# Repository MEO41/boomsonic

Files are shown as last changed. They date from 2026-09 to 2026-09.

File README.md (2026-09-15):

# boomsonic

**A 500 N-class turbojet and a ≤ 25 kg supersonic airframe, designed from first principles with open-source tools.**

Conceptual design study for an aircraft that must reach and hold **Mach 1** under the Boom Prize rules.
Design point: **500 N net thrust at M 1.02, 5 000 m ISA**.

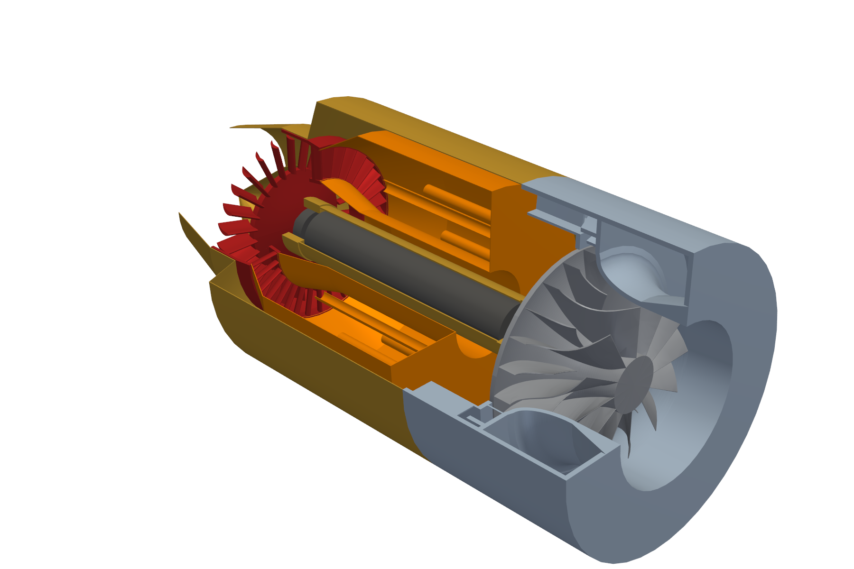
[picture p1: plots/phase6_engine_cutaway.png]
Engine cutaway


*Single-spool turbojet: centrifugal impeller and vaned diffuser (grey), annular vaporiser combustor (orange),
single-stage axial turbine (red). 187 mm diameter, 426 mm long, 6.85 kg.*

---

## Status

This is a **student learning project** and a **conceptual study**. Every number comes from a tool run or a cited
handbook relation, and the whole chain is reproducible from this repository — but **nothing has been built or
tested on hardware**, and several questions that decide whether this design survives are still open. They are
listed in [Open risks](#open-risks) and stated in full in [`docs/design_freeze.md`](docs/design_freeze.md).

Phases 0–6 are complete: requirements → airframe sizing → cycle and architecture trade → turbomachinery and rotor
dynamics → design freeze → CAD and 3D FE.

---

## What it came out as

### Engine — single-stage centrifugal turbojet

| | |
|---|---|
| Architecture | single spool: centrifugal compressor, annular combustor, axial turbine, convergent nozzle |
| Overall pressure ratio | 4.0 |
| Turbine inlet temperature | 1150 K |
| Airflow | 1.326 kg/s |
| TSFC | 0.164 kg/(N·h) |
| Spool speed | 75 000 rpm (105 % MCS = 78 750 rpm) |
| Impeller | Ti-6Al-4V, 12 main + 12 splitter blades, −15° exit backsweep, boreless hub |
| Impeller tip speed | 525 m/s (552 m/s at MCS) |
| Diffuser | vaneless gap, then 19 radial vanes to R4/R2 = 1.35, then axial deswirl |
| Turbine | single-stage axial, IN-713LC, 34 NGV / 28 rotor blades |
| Envelope / dry mass | **187 mm × 426 mm / 6.85 kg** |
| Sea-level static thrust | 631 N at 98.2 % speed (T4-limited) |

Efficiencies are quoted at the **fielded** level (η_c 0.70, η_t 0.75, η_b 0.95) — the level calibrated to reproduce
the TSFC of real commercial micro-turbojets, not the optimistic level the design tools predict.

### Aircraft — 0.30 m² wing, nose-pitot intake

| mass item | kg |
|---|---|
| engine (calibrated) | 6.85 |
| engine accessories | 1.60 |
| structure | 3.82 |
| landing gear + drag chute | 1.27 |
| fuel system | 0.40 |
| systems, avionics, instrumentation | 2.02 |
| growth allowance (15 %) | 1.13 |
| fuel (sortie + reserve + unusable) | 2.98 |
| **TOGW** | **20.09** |
| **margin to the 25 kg limit** | **4.91** |

| performance | nominal wave drag | pessimistic wave drag |
|---|---|---|
| **dash thrust margin at M 1.02 / 5 km** (target +25 %) | **+54.7 %** | **+28.5 %** |
| brake release to M 1.02 at 5 km | 27.7 s | 27.9 s |
| minimum excess thrust, transonic acceleration | 177 N | 116 N |
| 3 g sustained turn at M 0.9 / 5 km | +283 N | +283 N |
| ground roll / landing (flaps + chute) | 46 m / 175 m | |

> The **worst corner** (η_c 0.66, combustor +1σ, pessimistic drag) gives **+21.8 %, below the 25 % target.**
> It has not been re-run on the Phase 4 engine.

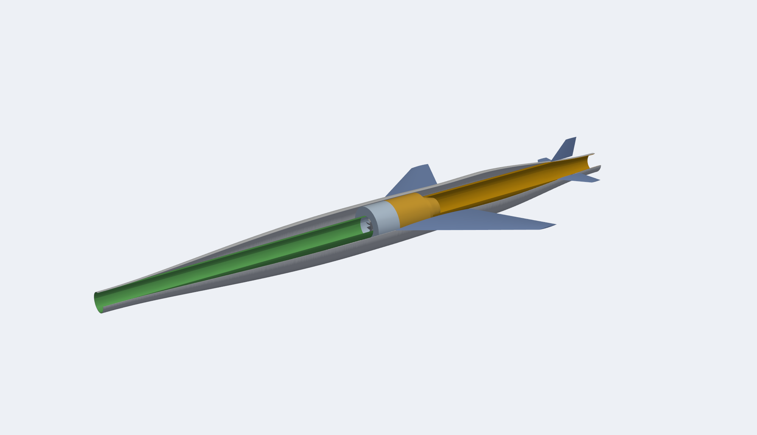
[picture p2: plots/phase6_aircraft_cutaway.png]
Aircraft cutaway


*Airframe with the intake duct (green), engine (grey/orange) and jetpipe (yellow). 2.7 m long, 217 mm fuselage
diameter, engine face at x = 1.315 m.*

---

## Selected results

### Architecture trade — why centrifugal

The Phase 3R trade swept OPR, spool speed and exit backsweep, screening each design for impeller stress feasibility
before evaluating it. Bars are engine diameter, calibrated dry mass, dash margin at pessimistic drag, and worst-corner
margin. The chosen point is OPR 4 / 75 krpm / −15°.

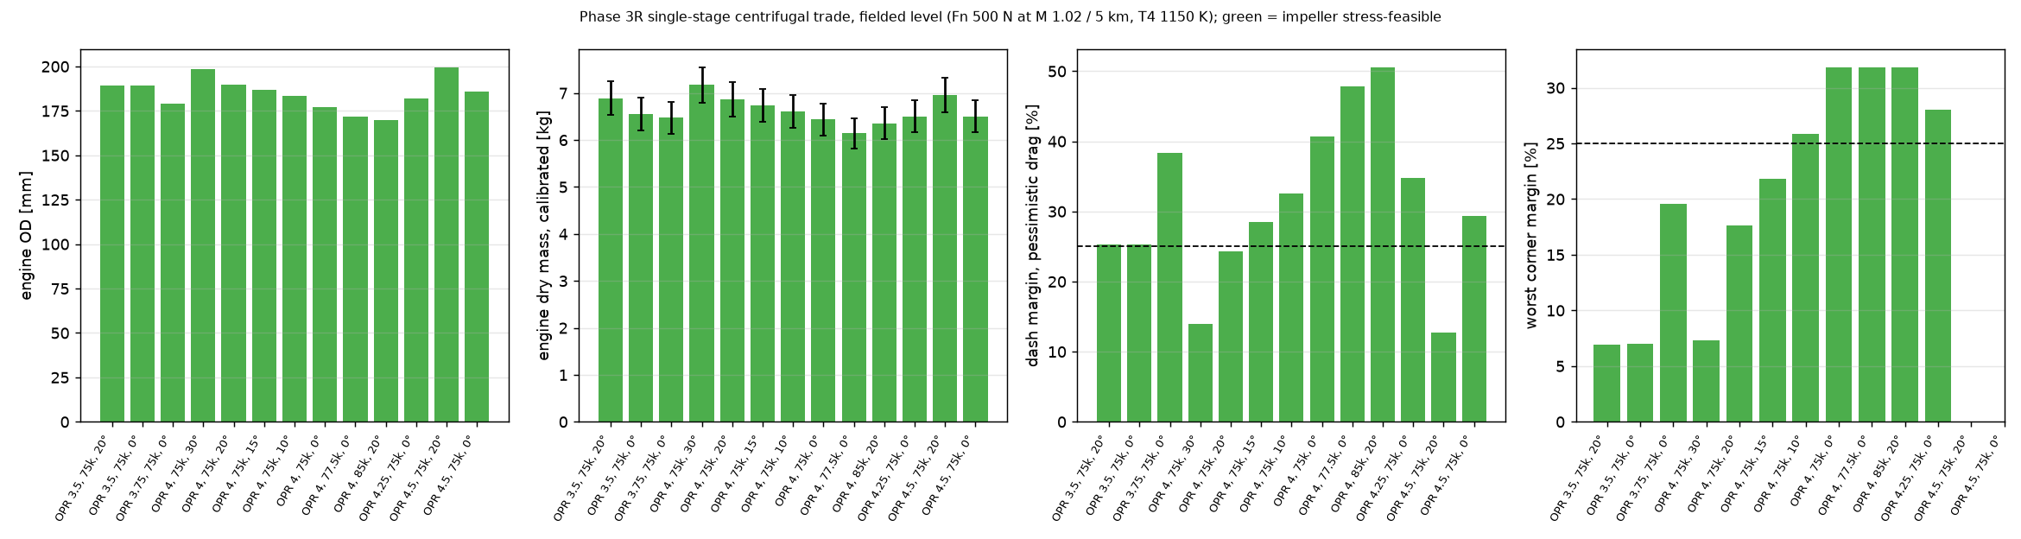
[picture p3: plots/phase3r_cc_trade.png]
Phase 3R centrifugal trade


### Off-design on real component maps

Thrust deck, sea-level-static running line and the flown sortie — computed in pyCycle with **TurboFlow-generated
compressor and turbine maps**, not placeholder map shapes.

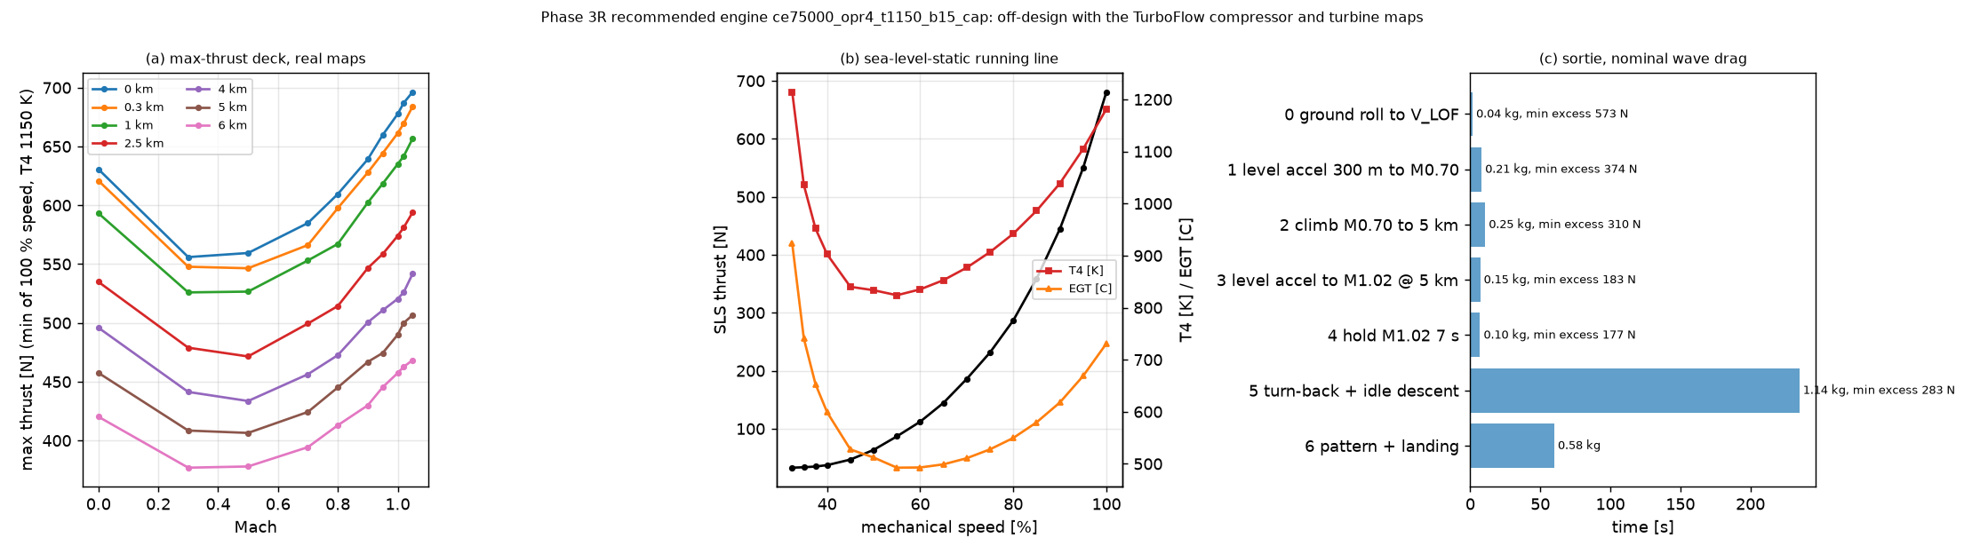
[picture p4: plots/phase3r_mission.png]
Phase 3R mission


### Rotor dynamics

Campbell diagram and mode shapes for the 32 × 25.6 mm tube shaft on damped supports. Three criticals at
8 335 / 14 383 / 105 571 rpm with amplification factors 2.64 / 1.28 / 29.09 — an **API-style separation-margin check
passes**, with the running range (grey) clear of the first two.

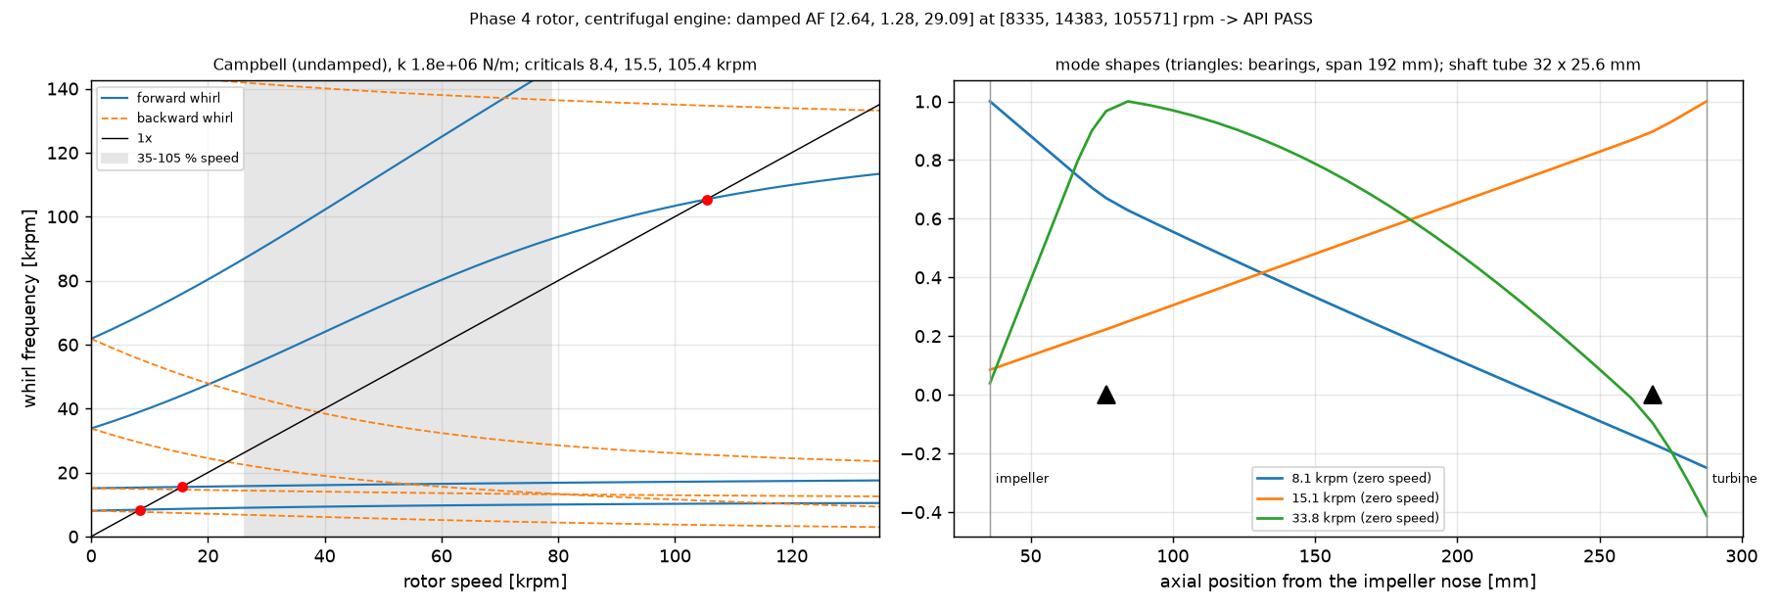
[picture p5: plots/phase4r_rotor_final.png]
Rotor dynamics


### 3D impeller stress

Cyclic-sector FE of the impeller passage, von Mises against Ti-6Al-4V minimum yield (622 MPa at temperature).
The exducer blade root sits on its limit by construction; the 3D model confirms the 1D sizing.

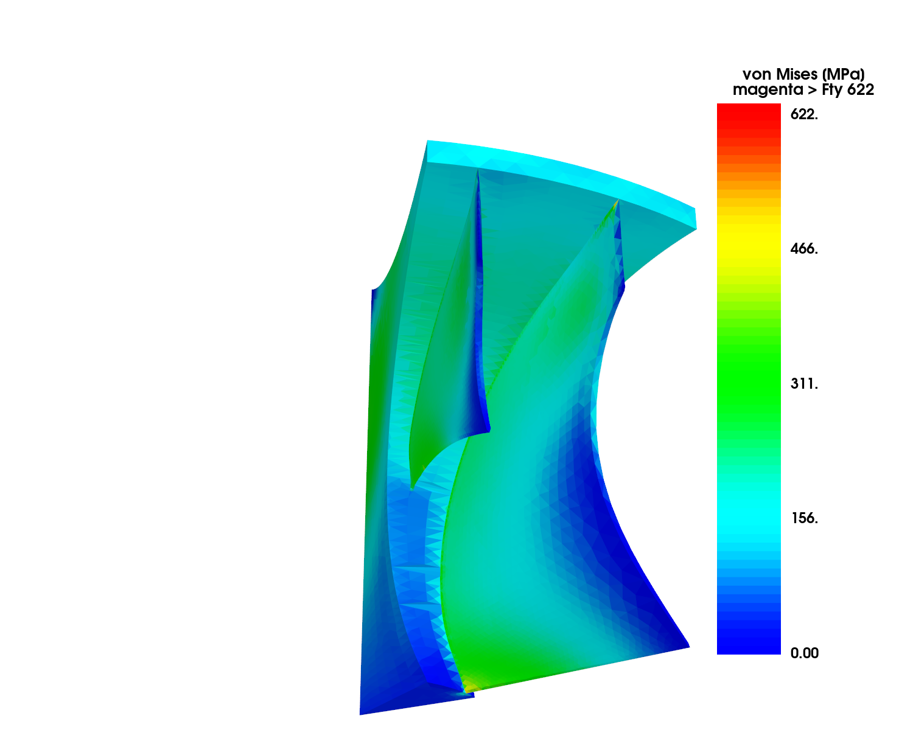
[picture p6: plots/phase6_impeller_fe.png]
3D impeller FE


More figures in [`plots/`](plots/) — constraint diagram, drag polar, area distribution, mass budget, cycle trade,
backsweep sweep, turbo-design cross-check, critical-speed map, and the CAD renders.

---

## Open risks

None of these is resolved. They are the reason this is a snapshot and not a closed design.

| risk | status |
|---|---|
| **Compressor surge margin** — no validated prediction method exists for a vaned-diffuser stage of this type. The peak-of-characteristic surrogate **failed its only validation** against NASA HECC data (measured 8.4 % vs surrogate ≥ 73 %). | **OPEN — top risk** |
| **Surge margin in the idle range** — 8.4–8.7 % on the ground running line; a start/handling bleed was proposed but never sized or integrated. | OPEN |
| **Combustor shortened 20 %** for rotor dynamics; combustion performance unverified at the shorter length. | OPEN |
| **Diffuser vane count excites the exducer at idle** — a live high-cycle-fatigue concern until the vane count is redesigned. | OPEN |
| **No rig or bench test.** Nothing here has been validated on hardware. | OPEN |
| Exducer root at yield at MCS by construction; turbine on its 350 MPa root limit; damped bearing cartridge not designed. | carried |

---

## How it was done

Every phase ends by handing the next decision to a human; nothing proceeds without that. Every non-trivial decision
is logged in [`design_log.md`](design_log.md) with the tool, the inputs, the outputs and why the choice won.

**Ground rule: no guessing.** Where a tool could not answer a question, that is recorded rather than filled in.

Tools are verified against closed-form or published results *before* being trusted, and the defects found along the
way are documented in [`tools_survey.md`](tools_survey.md) — including a genuine bug in TurboFlow's centrifugal slip
model (it takes `cos` of an angle in degrees), which is patched at run time and evidenced by a dedicated script.

| tool | used for |
|---|---|
| [pyCycle](https://github.com/OpenMDAO/pyCycle) / OpenMDAO | thermodynamic cycle, off-design, engine deck |
| [TurboFlow](https://github.com/turbo-sim/TurboFlow) | centrifugal compressor and axial turbine meanline design + maps |
| [turbo-design](https://github.com/nasa/turbo-design) (NASA) | independent centrifugal cross-check |
| [TurboDesigner](https://github.com/Turbodesigner/turbodesigner) | axial compressor meanline |
| [Cantera](https://cantera.org/) | combustion, real-gas check |
| [ADRpy](https://github.com/sobester/ADRpy) / [AeroSandbox](https://github.com/peterdsharpe/AeroSandbox) | constraint diagram, drag build-up |
| [ROSS](https://github.com/petrobras/ross) | rotor dynamics |
| [CadQuery](https://github.com/CadQuery/cadquery) + gmsh + scikit-fem | CAD, meshing, 3D FE |

---

## Repository layout

```
scripts/       phase0_tools/          tool smoke tests and verification
               phase1_requirements/   operating point and mission
               phase2_airframe/       constraint diagram, drag, mass budget
               phase3_cycle/          cycle model, architecture trade, centrifugal design
               phase4_turbomachinery/ maps, operability, stress, rotor dynamics
               phase6_cad/            CAD, 3D FE, rendering
               phase7_afterburner/    afterburner cycle, envelope, nozzle trade, closure
docs/          one report per phase; design_freeze.md is the status snapshot
data/          generated results (committed)
plots/         generated figures
cad/           STEP solids (engine_assembly.step, engine_with_afterburner_assembly.step)
axial/         the axial + axial-centrifugal branch, self-contained
```

The **axial branch is kept separate** under [`axial/`](axial/README.md). A 6-stage axial engine was taken to its own
freeze for comparison; it is not the baseline, and which architecture goes forward is still an open decision.
Keeping it in its own tree means axial numbers cannot leak into continued centrifugal work.

## Running it

Python 3.12 via [`uv`](https://github.com/astral-sh/uv), in three virtual environments (ADRpy and TurboFlow need
NumPy 1; pyCycle and the CAD stack need NumPy 2).

```powershell
uv venv --python 3.12 .venv      ; $env:VIRTUAL_ENV="$PWD\.venv";     uv pip install -r requirements-np2.txt
uv venv --python 3.12 .venv-np1  ; $env:VIRTUAL_ENV="$PWD\.venv-np1"; uv pip install -r requirements-np1.txt
uv venv --python 3.12 .venv-cad  ; $env:VIRTUAL_ENV="$PWD\.venv-cad"; uv pip install -r requirements-cad.txt
```

Check the toolchain, then reproduce the baseline engine:

```powershell
.venv\Scripts\python scripts\phase0_tools\smoke_pycycle.py                          # toolchain check
.venv\Scripts\python scripts\phase3_cycle\cc_trade.py run 4.0:75000:-15             # the baseline engine
.venv\Scripts\python scripts\phase3_cycle\cc_mission.py ce75000_opr4_t1150_b15_cap  # deck + sortie on real maps
.venv\Scripts\python scripts\phase4_turbomachinery\cc_closure.py                    # airframe mass closure
```

Phase 7 (afterburner) — verify first, then the study:

```powershell
.venv\Scripts\python scripts\phase7_afterburner\verify_ab_cycle.py      # regression + closed form + Cantera
.venv\Scripts\python scripts\phase7_afterburner\ab_envelope.py --regress # dry deck vs the frozen deck
.venv\Scripts\python scripts\phase7_afterburner\ab_design_point.py      # Tt7 sweep, duct Mach, thermal choking
.venv\Scripts\python scripts\phase7_afterburner\ab_envelope.py          # how far past Mach 1, on real maps
.venv\Scripts\python scripts\phase7_afterburner\ab_hardware.py          # diffuser, flameholder, Cantera stability
.venv\Scripts\python scripts\phase7_afterburner\ab_nozzle_trade.py      # three nozzle concepts + fixed reference
.venv\Scripts\python scripts\phase7_afterburner\ab_closure.py           # mass and 25 kg closure
.venv-cad\Scripts\python scripts\phase7_afterburner\ab_cad.py          # CAD: engine_with_afterburner_assembly.step
.venv-cad\Scripts\python scripts\phase7_afterburner\ab_render.py       # plots/phase7_ab_cutaway.png, _section.png
```

Full per-phase command reference: [`docs/running_the_code.md`](docs/running_the_code.md).

## Documents

| | |
|---|---|
| [`turbojet_500N_mission_brief.md`](turbojet_500N_mission_brief.md) | the brief and its binding ground rules |
| [`docs/design_freeze.md`](docs/design_freeze.md) | **status snapshot: the design and every open risk** |
| [`docs/phase3r_centrifugal.md`](docs/phase3r_centrifugal.md) | cycle and centrifugal compressor design |
| [`docs/phase4r_centrifugal.md`](docs/phase4r_centrifugal.md) | maps, operability, stress, rotor dynamics |
| [`docs/phase6_cad.md`](docs/phase6_cad.md) | CAD, 3D FE, airframe integration |
| [`docs/phase7_afterburner.md`](docs/phase7_afterburner.md) | afterburner: +79 % thrust, what actually caps the envelope, the nozzle trade |
| [`design_log.md`](design_log.md) | every decision, with numbers |
| [`tools_survey.md`](tools_survey.md) | tool survey and the defects found |
| [`axial/README.md`](axial/README.md) | the axial branch |

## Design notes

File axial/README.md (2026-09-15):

# `axial/` — the axial and axial-centrifugal compressor work

Everything in this directory belongs to engine architectures that are **not** the project baseline.
It is kept for the record and is separated from the repo root so that continued development of the
**centrifugal** engine cannot pick up an axial number by accident.

| | |
|---|---|
| **Status** | Not the baseline. Which engine goes forward is still an open decision of `docs/design_freeze.md`. |
| **Pure axial** | 6 stages, OPR 5, 80 000 rpm, tag `ax80000_opr5_t1150_n6_cap_3r`. Taken to its own freeze: `axial/docs/design_freeze_axial.md`. |
| **Axial-centrifugal ("option B")** | 1–2 axial stages + 1 centrifugal, Phase 3b / Phase 4. Superseded; kept for the record only. |
| **Open risks** | Unchanged by this reorganisation. The axial freeze's open risks (unvalidated stacking model R4.1, idle 77.5 % forcing an engine-off descent, unsourced variable-geometry hardware, start not analysed, blade roots at 96 % of Fty, blade resonances) and the Phase 6A risks R6A.1–R6A.6 must not be presented as resolved. |

## Layout

```
axial/
  scripts/
    phase3_cycle/           ax_trade.py, axial_sweep.py, axicent_sensitivity.py
    phase4_turbomachinery/  ax_*.py (Phase 4A), operability.py + sweeps (Phase 4 axial),
                            ac_operability.py / impeller_check_ac.py / plot_optionB.py (option B),
                            axial_blockage_screen.py, check_turbodesigner_blockage.py
    phase6a_axial_cad/      packaging and mass CAD of the axial core + variable geometry
  data/
    phase3ax/   phase3ax_trade.csv        Phase 3A-R cycle/compressor designs
    phase4ax/                             Phase 4A operability, rotor, mission, closure
    phase4/                               Phase 4 axial + option-B maps (TurboFlow), map parts
    phase6a/                              Phase 6A parameters, clash, mass
    phase4_*.csv|json                     Phase 4 axial running lines, sweeps, rotordynamics
    phase3_axicent_*.csv                  option-B screens and sensitivity
  docs/                     phase4a_axial.md, design_freeze_axial.md, phase4_operability.md,
                            phase4_rotordynamics.md, phase4_optionB_checks.md, phase6a_axial_cad.md
  plots/                    phase4a_*.png, phase4_operability.png, phase4_optionB_operability.png,
                            phase4_campbell.png, phase4_critical_speed_map.png, phase4_rotor_*.png
  cad/
    parts/                  axial core + variable-geometry STEP solids
    axial_core_assembly.step, axial_vg_assembly.step
```

## How the split works

Scripts here keep **two** roots:

* `ROOT` — the repo root, unchanged in meaning. Shared modules (`cycle_model`, `arch_trade`,
  `engine_mass`, `rotor_model`, `cadlib`, …) and shared data (`data/phase3/`, `data/phase3r/`) are
  still reached through it, so nothing was duplicated.
* `AXROOT` — this directory. Every axial artefact (data, plots, cad) is written and read through it.

Each script inserts its original shared directory on `sys.path`, so its imports resolve exactly as
before the move.

### Five axial-named modules deliberately stayed in the shared tree

They could not move: the live **centrifugal** entry points import them.

| module (still in `scripts/`) | imported by | what is used |
|---|---|---|
| `phase3_cycle/axial_design.py` | `arch_trade.py` (module level) → `cc_trade.py` | axial meanline design, for the architecture trade |
| `phase3_cycle/axicent_design.py` | `arch_trade.py` (module level) → `cc_trade.py` | axial-centrifugal design, for the architecture trade |
| `phase4_turbomachinery/axial_map.py` | `cc_mission.py`, `cc_benchmark.py` | `build_compressor_lines`, `compressor_mapdata`, `turbine_mapdata` — generic map → pyCycle helpers, not axial-specific |
| `phase4_turbomachinery/axial_offdesign.py` | `cc_mission.py`, `cc_benchmark.py`, `ac_offdesign.py` | the `Choked` exception; `Compressor` only on the axial path |
| `phase4_turbomachinery/ac_offdesign.py` | `cc_mission.py`, `cc_benchmark.py` | `PureCC` and `CentrifugalMap` — the **pure centrifugal** off-design model lives in this file |

`rotordynamics.py`, `rotordynamics_damped.py`, `rotordynamics_stiffening.py` and `rotor_model.py`
also stayed, because `cc_rotor.py` imports them. Their `__main__` studies are the pure-axial rotor,
so those scripts write their results here, into `axial/data/` and `axial/plots/`.

## Commands

Run from the **repo root**, as before.

### Phase 3A-R / 4A (pure axial, taken to its freeze)

```powershell
.venv\Scripts\python axial\scripts\phase3_cycle\ax_trade.py grid                     # fielded compressor grid (P3_DATA=phase3ax set inside)
.venv\Scripts\python axial\scripts\phase3_cycle\ax_trade.py run 80000                # full chain at one speed (omit rpm: all speeds)
.venv\Scripts\python axial\scripts\phase3_cycle\ax_trade.py compile                  # axial/data/phase3ax_trade.csv
$t = "ax80000_opr5_t1150_n6_cap_3r"
.venv\Scripts\python axial\scripts\phase4_turbomachinery\ax_rotor_stress.py $t       # blade roots, discs, blade modes (+ FE verification)
.venv\Scripts\python axial\scripts\phase4_turbomachinery\ax_operability.py $t one 15 0.10 1.6   # one VG configuration per process (parallel)
.venv\Scripts\python axial\scripts\phase4_turbomachinery\ax_operability_summary.py $t          # idle per configuration (AXOP_SM_MIN)
$env:AXOP_A8_N = "0.80"; .venv\Scripts\python axial\scripts\phase4_turbomachinery\ax_operability.py $t final 15 0.10 2.0   # adopted VG
.venv\Scripts\python axial\scripts\phase4_turbomachinery\ax_rotor.py $t 80           # rotor-dynamics sweep (ROSS); 2nd arg = idle % for the API check
.venv\Scripts\python axial\scripts\phase4_turbomachinery\ax_transient.py $t          # acceleration (~45 min; AXTR_NS=0.8,0.775 re-runs a subset)
.venv\Scripts\python axial\scripts\phase4_turbomachinery\ax_mission.py $t            # engine deck + idle (AXM_REUSE_DECK=1 reuses the deck)
.venv\Scripts\python axial\scripts\phase4_turbomachinery\ax_closure.py $t            # engine update + closure (incl. engine-off descent)
.venv\Scripts\python axial\scripts\phase4_turbomachinery\ax_plots.py $t              # axial/plots/phase4a_*.png
```

### Phase 6A (axial packaging and mass CAD; exploratory only)

```powershell
.venv\Scripts\python axial\scripts\phase6a_axial_cad\make_params_axial.py    # parameter sheet + VG actuation loads
.venv\Scripts\python axial\scripts\phase6a_axial_cad\ax_flowpath_check.py    # flow-path area / choking capacity per station
.venv-cad\Scripts\python axial\scripts\phase6a_axial_cad\ax_engine_cad.py    # core engine solids -> axial/cad/parts/
.venv-cad\Scripts\python axial\scripts\phase6a_axial_cad\ax_vg_cad.py        # VIGV, stage-3 bleed, variable nozzle mechanisms
.venv-cad\Scripts\python axial\scripts\phase6a_axial_cad\ax_clash.py         # envelope, interference, clearances (~3 min)
.venv-cad\Scripts\python axial\scripts\phase6a_axial_cad\ax_mass_compare.py  # CAD vs the raw bottom-up mass model
```

### Phase 4 on the early pure axial (operability, rotor dynamics)

The map runners live in the shared tree and are steered by environment variables; point `MAP_DIR`
at `axial/data/phase4` for axial tags.

```powershell
.venv\Scripts\python axial\scripts\phase4_turbomachinery\check_turbodesigner_blockage.py   # evidence for the Phase 3 blockage error
$env:P3_OPR=5; $env:P3_CASES="axial:0"; $env:P3_TURB_CAP=1; $env:P3_CC_REF=0.794; $env:P3_TAG_SUFFIX="_blk"; .venv\Scripts\python scripts\phase3_cycle\arch_trade.py
$env:MAP_DIR="axial/data/phase4"; bash scripts/phase4_turbomachinery/run_turbine_map.sh ax0_opr5_t1150_cap_blk
.venv\Scripts\python axial\scripts\phase4_turbomachinery\operability.py ax0_opr5_t1150_cap_blk      # stacking map, running lines, variable IGV
.venv\Scripts\python axial\scripts\phase4_turbomachinery\nozzle_sweep.py ax0_opr5_t1150_cap_blk 1.3,1.6,2.0
.venv\Scripts\python axial\scripts\phase4_turbomachinery\bleed_sweep.py ax0_opr5_t1150_cap_blk 0.1,0.2,0.3
.venv\Scripts\python axial\scripts\phase4_turbomachinery\running_line_axi5.py                      # bracket with the NPSS AXI5 map
.venv\Scripts\python axial\scripts\phase4_turbomachinery\plot_operability.py
.venv\Scripts\python scripts\phase4_turbomachinery\rotordynamics_verify.py   # shared: ROSS verification (writes data/phase4_rotordynamics_verification.json)
.venv\Scripts\python scripts\phase4_turbomachinery\rotordynamics.py          # shared module, axial study -> axial/data, axial/plots
```

### Option B checks (axial-centrifugal) and method benchmark

```powershell
.venv\Scripts\python axial\scripts\phase4_turbomachinery\impeller_check_ac.py    # check 1: impeller stress, both AC variants
$env:MAP_DIR="axial/data/phase4"; bash scripts/phase4_turbomachinery/run_centrifugal_map.sh ax90000_opr4_t1150_ax2_pa2_cap_blk
.venv\Scripts\python axial\scripts\phase4_turbomachinery\ac_operability.py ax90000_opr4_t1150_ax2_pa2_cap_blk [neg_width] [cc map]
.venv\Scripts\python axial\scripts\phase4_turbomachinery\plot_optionB.py
```

`cc_benchmark.py` (the same chain on the JetCat P400 model) stayed in the shared tree — it is the
method verification for the centrifugal too. Its pre-Phase-3R P400 maps stayed in `data/phase4/`.

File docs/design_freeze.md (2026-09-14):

# Design freeze (Phase 5): status snapshot for review (2026-09-14)

**What this document is.** It is the brief's Phase 5 deliverable: a snapshot of the current design, compiled from Phase
3R (`docs/phase3r_centrifugal.md`) and Phase 4R (`docs/phase4r_centrifugal.md`) for the user's review. **It does not
claim the design is closed.** Several items that decide whether this geometry survives are still open, and section 4
states them with their current status. Per the brief, Phase 6 (CAD / 3D) does not start without the user's explicit
sign-off.

Every number here comes from a tool run or a cited relation (sources in the two phase reports and `design_log.md`).
Nothing has been measured on hardware. Numbers are given at the **fielded** technology level (η_c 0.70, η_t 0.75,
η_b 0.95, the level that reproduces commercial micro-turbojet TSFC) unless marked "tool".

---

## 1. Final architecture

Single-spool turbojet with a single-stage centrifugal compressor, annular combustor, single-stage axial turbine and
convergent nozzle, in a nose-pitot-fed fuselage.

### 1.1 Cycle (design point: Fn 500 N at M 1.02 / 5000 m ISA, T4 1150 K)

| quantity | fielded | tool level |
|---|---|---|
| net thrust / T4 | 500 N / 1150 K | 500 N / 1150 K |
| overall pressure ratio | 4.0 | 4.0 |
| airflow | 1.326 kg/s | 1.068 kg/s |
| fuel flow / TSFC | 0.0228 kg/s / 0.164 kg/(N h) | - / 0.138 kg/(N h) |
| compressor inlet (after intake) | 309 K, 102.1 kPa (normal shock 0.99999, subsonic duct loss 3.05 % of Pt) | |
| compressor exit | 520 K, 408 kPa | 490 K |
| turbine inlet / exit | 1150 K, 388 kPa / 972 K (699 C) | |
| turbine pressure ratio (tt) | 2.60 | |
| nozzle | convergent, A8 70.8 cm², NPR 2.76 | |
| fuel-air ratio / overall φ | 0.0163 / 0.244 | |

* Real-gas check: Cantera (n-dodecane surrogate) against pyCycle at the combustor exit gives T4 -4.0 K (-0.35 %),
  γ +0.0002, cp +0.6 %.
* Sea-level static: 631 N at 98.2 % speed, limited by T4. 100 % speed would need T4 1182 K.

### 1.2 Compressor: single-stage centrifugal (`ce75000_opr4_t1150_b15_cap`)

| item | value |
|---|---|
| spool speed | 75 000 rpm; MCS (105 %) 78 750 rpm |
| why 75 000 rpm | inducer shroud relative Mach 1.29 at the fielded airflow, inside the range of 9 fielded micro-turbojets (1.10-1.33) |
| impeller | Ti-6Al-4V, **12 main + 12 splitter blades**, **exit backsweep -15°**, boreless hub with back-face boss |
| impeller exit radius / tip speed | 66.9 mm (D2 134 mm) / 525 m/s (552 m/s at MCS); tool level 61.9 mm / 486 m/s |
| eye tip / hub radius | 49.7 / 17.4 mm |
| exit width, effective / physical | 10.7 / 11.8 mm (blade blockage 9 %; corrected in Phase 6 from a transcription "12.0", data 11.796 mm) |
| exducer blade root | 2.24 mm, tapering to 0.8 mm; sized so its peak stress at MCS equals the minimum yield (Kt 1.4) |
| inducer throat | area ratio 0.75 of the eye (10 % choke margin at design speed) |
| diffuser | vaneless gap to 1.06 r2, then a **19-vane** radial vaned diffuser to R4/R2 1.35, then an axial deswirl; exit Mach 0.21 |
| efficiency (η_tt) | tool: TurboFlow 0.817, NASA turbo-design 0.803 (PR 4.05 vs 4.01, same geometry); fielded 0.70 |

**Impeller stress at MCS** (Ti-6Al-4V, minimum basis Fty 620 / Ftu 681 MPa at ~250 C):
* exducer root 618 MPa, equal to Fty by construction;
* inducer root 196 MPa;
* disc 335 MPa with the thermal gradient (+86 % yield margin);
* burst ratio 1.90 (>= 1.20 required).

### 1.3 Turbine: single-stage axial

| item | value |
|---|---|
| material / blades | IN-713LC; **34 NGV / 28 rotor blades**; blade heights 23 / 24 mm |
| tip radius | 61.1 mm, **exactly on the 350 MPa blade-root stress limit** at 75 000 rpm (conceptual allowable, A3.2) |
| turbine OD | 127 mm (inside the engine envelope) |
| efficiency (η_tt) | tool 0.936 (TurboFlow; 0.933 re-designed at the fielded flow); fielded 0.75 |

### 1.4 Combustor, rotor, envelope

| item | value |
|---|---|
| combustor | annular; casing OD 183.6 mm (grown to the diffuser envelope in Phase 4); inner radius 22.6 mm; **liner 150 mm** (0.8 × the Phase 3 rule of 3 × annulus height); reference velocity 23.6 m/s; η_b 0.95 and dP/P 0.05 assumed |
| rotor | overhung impeller and overhung turbine on two hybrid ball bearings in the shaft tunnel; **AISI 4340 tube shaft 32 × 25.6 mm**, 12 mm journals; **bearing span 192 mm**; damped soft supports (k ~1.75e6 N/m, c ~900 N s/m); rotor 2.11 kg, Ip 2.13e-3 kg m² |
| **engine envelope** | **OD 187 mm** (186.6, set by the compressor diffuser; combustor 183.6, turbine 127) × **length 426 mm** |
| **engine dry mass** | **6.85 kg** calibrated (bottom-up 5.70 kg × 1.20 from the JetCat P400 / AMT Nike validation; range 6.49-7.21 kg) |

Largest raw mass items (kg, before calibration):
* impeller 0.92;
* outer casing 0.73;
* shaft 0.58;
* combustor liners 0.54;
* shroud / inlet 0.44;
* diffuser and deswirl 0.39;
* shaft tunnel and bearing housings 0.35;
* turbine disc 0.28.

Accessories (ECU, pump, etc.) are carried separately: 1.60 kg (A3.7).

---

## 2. Airframe closure (S 0.30 m², Phase 2 airframe; `cc_closure.py`, `data/phase4r_closure.json`)

Fuel comes from the sortie flown on the engine's real-map deck: TurboFlow compressor and turbine maps in pyCycle,
T4-limited max throttle. TOGW is iterated on that fuel.

| mass item | kg |
|---|---|
| engine (calibrated) | 6.85 |
| engine accessories | 1.60 |
| structure | 3.82 |
| landing gear + drag chute | 1.27 |
| fuel system | 0.40 |
| systems, avionics, prize instrumentation | 2.02 |
| growth allowance (15 %) | 1.13 |
| fuel: sortie 2.36 + 120 s idle reserve 0.54, + 3 % unusable | 2.98 |
| **TOGW** | **20.09** |
| **margin to 25 kg** | **4.91** |

| performance check | nominal wave drag | pessimistic wave drag |
|---|---|---|
| **dash thrust margin at M 1.02 / 5 km** (target 25 %) | **+54.7 %** | **+28.5 %** |
| minimum excess thrust, transonic acceleration at 5 km | 177 N | 116 N |
| brake release to M 1.02 at 5 km | 27.7 s | 27.9 s |
| 3 g sustained turn at M 0.9 / 5 km, excess thrust | +283 N | +283 N |

* **Worst corner** (η_c 0.66, combustor +1 σ, pessimistic drag): **+21.8 %, below the 25 % target.** It was evaluated
  in Phase 3R, before the Phase 4 engine changes (the diameter and cycle did not change; the mass rose 0.11 kg), and has
  not been re-run on the Phase 4 engine.
* **Take-off:** ground roll **46 m**, V_LOF 48.6 m/s.
* **Landing** at 17.7 kg (Phase 2 model, μ_brake 0.3): **175 m with flaps and the 0.6 m drag chute**; 194 m chute
  without flaps; **316 m with flaps only**. Against the 300 m runway assumption (A1.7) the chute is required.
* Diameter sensitivity: the one validation engine whose diameter the compressor sets (AMT Nike) is over-predicted by
  5.7 %. Calibrating to it gives 177 mm and +67 / +42 % margin. It is not applied.

---

## 3. Rotor dynamics (`docs/phase4r_centrifugal.md` section 5, `plots/phase4r_rotor_final.png`)

**Result: API 684 / 617 separation criteria met** (ROSS, verified; damped criticals with squeeze-film / O-ring supports;
operating range 35-105 %, i.e. 26-79 krpm):

| critical | amplification factor | position | requirement |
|---|---|---|---|
| 8.3 krpm (rigid-body mode) | 2.64 | 68 % below the minimum operating speed | 5 % |
| 14.4 krpm (rigid-body mode) | 1.28 | below idle, critically damped | none |
| **105.6 krpm (first shaft bending)** | 29 | **34 % above MCS** | 25.8 % |

The bending mode is 34 krpm at rest. The gyroscopic moments of the overhung impeller and turbine stiffen its forward
branch, which puts the synchronous crossing at 105.6 krpm.

**What it took.** As first laid out (Phase 3 combustor rule, 235 mm bearing span), the first bending critical sat at
38-59 krpm for 16-28 mm shafts, inside the running range. The bearings carry only 4 % of that mode's strain energy, so
dampers cannot help. Its frequency is set by the bearing span, which is mostly the combustor. The fix:
1. **Combustor shortened 20 %** (liner 188 → 150 mm; span 235 → 192 mm) **and grown outward** into the free room under
   the diffuser (OD 170 → 184 mm, no engine-diameter cost). Liner volume is 94 % of the Phase 3R combustor, and the
   volume-corrected loading parameter is 0.92 × the 7-engine reference mean (-0.42 σ of their spread; Phase 3R was 1.00).
   That is near parity, not exact.
2. **Thin-wall shaft tube 32 × 25.6 mm** (ID/OD 0.8, more stiffness per unit mass), with 12 mm journals (bearing DN
   0.95e6 at MCS).
3. **Damped soft bearing mounts** (k ~1.75e6 N/m, c ~900 N s/m) for the two rigid-body modes.

Bearing loads: 16.5 N front / 4.2 N rear at 1 g; gyroscopic 87 N per rad/s of pitch or yaw rate.

**The pass holds only for this span and shaft.** In the stiffening sweep, lengthening the span by about 11 mm (liner ×0.85
instead of ×0.80) dropped the bending critical from 105 to 96 krpm with the same 32 mm tube and 12 mm journals, below
the 99 krpm requirement.

---

## 4. Open risks (current status; none of these is resolved)

### 4.1 Compressor surge margin: no validated prediction method exists for this stage type. OPEN, top risk.
* **What is known.** Design-point pressure ratio and efficiency are confirmed by two independent tools (TurboFlow and
  NASA turbo-design agree within 1 % on PR and 1.5 points on efficiency). The surge line is not known.
* **The two tools disagree on the same impeller.** Design-point surge margin by the peak-of-characteristic surrogate:
  **28 % (TurboFlow)** against **6.5 % (turbo-design)**. turbo-design's 100 % speed line is nearly flat (PR within 1.3 %
  from 70 % to 108 % of design flow), so its peak is ill-defined.
* **The surrogate itself failed its only validation against real data** (`hecc_surge_check.py`). On NASA's HECC stage
  (measured to surge):
  * measured design-point surge margin **8.4 %**, with the pressure ratio still rising at the last stable point
    (95 % of design flow);
  * turbo-design's characteristic keeps rising down to 61 % of design flow, so the surrogate implies >= 73 %: wrong by
    roughly an order of magnitude.
* **Why.** In a vaned-diffuser stage, surge is triggered by diffuser (vane) stall. **Neither tool models diffuser
  stall.** Every surge-margin number in Phase 3R and Phase 4R (the 28 % design margin, 22-27 % on the ground running
  line, and the acceleration limits) comes from this unvalidated surrogate.
* **What the -15° backsweep choice rests on.** Both tools and the textbooks agree on the direction (more backsweep, more
  stability). The magnitude is not validated. The backsweep was chosen mid-window on the TurboFlow numbers.
* **Status of mitigation:** **a diffuser redesign for wider stall range was recommended** (fewer or low-solidity vanes,
  larger vaneless gap) **but has not been run.** Alternatives listed but not evaluated:
  * a vaneless diffuser;
  * -20° backsweep (+11 to +14 points of surrogate margin, dash margin +24 %);
  * a variable nozzle;
  * rig test.

  No approved tool currently predicts vaned-diffuser stall; this needs a sourced diffuser-stall method or test data.

### 4.2 Surge margin in the idle range: a separate, sharper transient risk. OPEN.
* **Ground running line** (TurboFlow surrogate, `phase3r_mission_..._running_lines.csv`): surge margin 8.4-8.7 % at
  35-40 % speed and 13 % at 45 %, against 22-27 % above 55 %. These are the same surrogate as 4.1, so the real values
  may be lower.
* **Effect on acceleration** (`cc_transient.py`; T4 <= 1150 K):
  * **with a 5 % transient reserve**, 40 → 95 % takes 6.6 s, and almost half of it is spent between 40 and 45 %, where
    the surge margin, not the temperature, holds the excess power to about 0.5 kW;
  * **with a 10 % reserve the engine cannot accelerate from 40 % at all.**
* This is independent of the diffuser outcome: the idle-range margin is thin even by the optimistic surrogate.
* **Status: a start / handling-bleed provision was proposed but has not been sized or integrated** (no port location,
  valve, schedule, or effect on the cycle and the mass). A higher idle (45 %) also shortens the acceleration to 3.5 s;
  it is not adopted.

### 4.3 Combustor shortened 20 % for rotor dynamics: combustion performance unverified. OPEN.
* The liner is 150 mm, 2.2 × annulus height, against the 3.0 rule used through Phase 3R.
* The sizing basis (Lefebvre theta scaled on 7 fielded engines) has no length term. Treating liner volume as the
  residence measure puts it at -0.42 σ of the reference spread.
* Combustion efficiency, pattern factor, pressure loss (0.05 kept) and lean stability at this length have **not been
  checked by any tool or data**.
* If the combustor has to get longer again, the rotor pass in section 3 is lost (see 5).

### 4.4 Diffuser vane count excites the exducer at idle: vibration / fatigue. OPEN.
* Screening modal model (Morley plate, verified -1.5 %; static frequencies): exducer mode 1 at 9.33 kHz **crosses the
  19-vane passing frequency at 39 % speed, i.e. at idle**, where the engine dwells. Mode 2 (16.0 kHz) crosses at 67 %.
* Centrifugal stiffening, which raises the crossings somewhat, is not modelled. No forced-response or damping estimate
  exists.
* **This is a live high-cycle-fatigue concern until the vane count is redesigned.** 15-17 vanes would move the static
  crossings off idle and full power. That choice belongs with the diffuser redesign in 4.1, which has not been run.

### 4.5 Nothing has been validated by a rig or bench test. OPEN.
Every number in this document is tool-predicted:
* cycle and component efficiencies (fielded level set by vendor TSFC data);
* maps and operability;
* stresses;
* rotor dynamics;
* mass (calibrated on two engines);
* mission.

The only hardware anchors are published data sheets (TSFC, mass, length, idle) and NASA's HECC measurements, which
were used as checks, not as tests of this design.

### 4.6 Other open items (carried; each is documented in the phase reports)
| item | status |
|---|---|
| **impeller exducer root at Fty at MCS by construction** | zero margin above the 105 % speed basis; 3D FE (rake / lean), low-cycle fatigue for start-stop cycles not done |
| **turbine on its 350 MPa blade-root limit** | conceptual allowable (A3.2); IN-713LC life data needed |
| **damped bearing supports** | cartridge design, temperature, nonlinearity not modelled; mass not separately sourced (inside the housing allowance) |
| bearing DN 0.95e6 at MCS | at the edge of the 1e6 micro-gas-turbine reference |
| **diffuser sets the engine diameter** | R4/R2 1.35 not optimised (no approved tool can size it); the Nike check suggests about 10 mm conservatism |
| worst-corner thrust margin +21.8 % | below 25 %; not re-run on the Phase 4 engine |
| fielded technology level (η_c 0.70, η_t 0.75, η_b 0.95) | from vendor TSFC; the design has no efficiency data of its own |
| mass calibration ×1.20 (1.14-1.27) | two reference engines |
| compressor map above 105 % corrected speed | missing (cold, low-Mach corner of the deck above 2.5 km: no surge margin computed there) |
| idle fuel 19 % of max | fielded engines 14-18 %; the model's low-speed end is ~5 points of speed pessimistic (P400 benchmark) |
| drag chute | required for a 300 m runway |
| Phase 2 climb segment | not flight-path limited at T/W > 1 (optimistic time, small fuel effect) |
| TurboFlow slip patch | every compressor result depends on `turboflow_fixes.py` (upstream defect) |

---

## 5. What Phase 6 (CAD / 3D) would start from if approved now

**Geometry that would be committed:** the section 1 design:
* impeller: 134 mm, 12 + 12 blades, -15°, 2.24 mm exducer root;
* diffuser: 19-vane radial vaned, R4/R2 1.35, plus axial deswirl;
* combustor: OD 184 mm, 150 mm liner;
* turbine: single stage, tip 61.1 mm;
* rotor: 32 × 25.6 mm tube shaft, 12 mm journals, 192 mm bearing span, damped soft mounts;
* envelope: 187 × 426 mm.

**Proceeding to CAD before the diffuser redesign and the surge-margin question (4.1, 4.2, 4.4) are resolved means
committing geometry that may have to change.** In particular:
* **The diffuser is the most likely part to change**: vane count and type, radius ratio, vaneless gap, possibly a
  vaneless diffuser. It sets the engine diameter (drag, and the dash margin at about 3 N per mm), the front-bearing
  housing (which sits in the diffuser hub), and the axial length ahead of the combustor.
* **The API rotor-dynamics pass assumed the current bearing span and shaft.** Anything that moves the front bearing
  aft, or lengthens the combustor (for example if 4.3 fails), eats into the bending-critical margin. About 11 mm more
  span was enough to fail the criterion in the sweep. A vaneless diffuser or -20° backsweep would also change the
  impeller's mass and inertia, which feed the rigid-body modes and the gyroscopic stiffening.
* **A start-bleed provision (4.2)** would add a port, a valve and ducting in the compressor or diffuser region that CAD
  would otherwise not reserve space for.
* **The combustor length (4.3)** is set by rotor dynamics, not by combustion data. A combustor result could force the
  combustor, the span and the shaft to change together.

The parts least likely to change are the cycle point, OPR 4 / 75 000 rpm, the turbine, and the airframe closure, which
has 4.9 kg of mass margin to absorb changes.

---

## 6. Decisions for the reviewer

1. **Surge margin (4.1 / 4.2):**
   * run the diffuser redesign for stall range, which needs a sourced diffuser-stall method;
   * or evaluate another mitigation: a vaneless diffuser, -20° backsweep, start bleed, or a variable nozzle;
   * or accept the risk to a rig test.
2. **Diffuser vane count (4.4):** together with (1).
3. **Combustor length (4.3):** accept 150 mm pending data, or require a combustor check first.
4. **Phase 6:** **not started.** Approve, defer until 1-3 are resolved, or approve with the diffuser and rotor
   (bearing span / shaft) explicitly held as provisional.

| | |
|---|---|
| Reviewer sign-off (Phase 5 → Phase 6) | not given |
| Date | |

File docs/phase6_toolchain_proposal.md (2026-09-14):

# Phase 6: CAD / 3D toolchain proposal (for confirmation before any geometry is generated) (2026-09-14)

The brief's Phase 6: "propose the CAD/3D toolchain (e.g. CadQuery/FreeCAD scripting) and confirm it with me before
generating any geometry". The user said "continue phase 6" after the Phase 5 snapshot (`docs/design_freeze.md`). The
freeze's open decisions (surge margin, diffuser vane count, combustor length) are **still open**. As the freeze
section 5 warns, geometry that depends on them may need to change. The proposal below builds those parts from
parameters so they can be regenerated rather than redrawn.

## 1. Proposed toolchain (installed and verified in `.venv-cad`)

| tool | role | verification |
|---|---|---|
| **CadQuery 2.8.0** (OCCT 7.9.3 via OCP, Apache-2.0) | scripted solid modelling, assembly, STEP and STL export; direct OCCT calls for B-spline surfaces through point clouds and lofts | `scripts/phase6_cad/smoke_cad.py`: exact box volume and STEP round trip; B-spline surface through cylinder points at the exact analytic area; spline-section loft at the exact analytic volume, valid solid |
| **pyturbo-aero 1.3.8** (NASA, held for Phase 6 since D0.7) | impeller blade geometry: main and splitter blades from the meridional hub / shroud, camber (metal angles, wrap) and thickness distributions, tip clearance, full wheel; point clouds only | imports; API present. A functional check on a generic case is the first step after confirmation. Known defect: shared class-level `patterns` list (build one wheel per process) |
| **gmsh 4.15.2** | tetra meshing of CAD solids for 3D FE (the freeze's open "3D impeller FE") | STEP box meshed, summed volume exact |
| scikit-fem 12.0.2 (existing, `.venv`) | 3D elasticity on the gmsh mesh, if the 3D impeller FE is pursued | would need its own 3D verification (rotating solid disc and cantilever) before use |

Environment: a separate `.venv-cad` (`requirements-cad.txt`), so the frozen analysis environments are untouched.
Geometry data passes from the analysis to CAD as JSON, as between the two existing venvs.

**Alternatives considered:**
* **build123d 0.11** has the same kernel, but its OCP build differs from CadQuery's (novtk), so it cannot share the env.
  CadQuery is the one the brief names.
* **FreeCAD scripting** needs a full application install and its own Python, and is harder to run headless and
  reproducibly.
* **OpenVSP** is not needed unless the airframe is modelled.

## 2. Proposed modelling plan (nothing below is generated until confirmed)

1. **Parameter sheet** `data/phase6/engine_params.json`, generated from the Phase 3R / 4R data files, so every CAD
   dimension is traceable. Each parameter is tagged *frozen* or *provisional*. Provisional, per the freeze:
   * diffuser vane count and type, R4/R2, vaneless gap;
   * combustor length and radius;
   * bearing span, shaft tube, bearing housings;
   * start-bleed provision (space reserved only).
2. **2D meridional layout** of the whole engine: flow path, stations, bearing positions, envelope. Checked against the
   mass-model envelope (426 × 187 mm).
3. **Impeller 3D** (pyturbo-aero → CadQuery solid): hub body with boreless back-face boss, 12 + 12 blades, -15°
   backsweep, the stress-sized root thickness distribution, tip clearance.

   Checks against the analysis:
   * blade count and exit angle;
   * eye and exit radii and widths;
   * inducer throat area against the design's 0.75 of the eye area;
   * mass and inertia against the axisymmetric FE body (1.13 kg, Ip 1.44e-3 kg m² before the 10 % allowance).
4. **Other components as conceptual solids:**
   * vaned diffuser and deswirl (parametric vane count);
   * combustor casing and liners;
   * NGV and turbine from the TurboFlow blade geometry;
   * shaft, bearings and damper housings;
   * outer casing and nozzle.

   Assembled into one STEP file.
5. **Optional further analysis on the CAD:** 3D FE of the impeller blades (gmsh + scikit-fem, verified first) to replace
   the 2D plate model of the exducer root; CAD mass properties against the models.

Not proposed unless asked:
* airframe CAD;
* detail or manufacturing drawings, tolerances, fillets beyond the root fillet the stress sizing assumes.

## 3. What the user is asked to confirm
* the toolchain (section 1);
* the scope and order (section 2), in particular engine only or also the airframe, and whether the optional 3D FE is
  in;
* that provisional parts are modelled parametrically, while their decisions stay open in `docs/design_freeze.md`.

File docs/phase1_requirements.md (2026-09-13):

# Phase 1 — Requirements, operating point and mission definition (2026-09-13)

Context (from the user): RC-scale student project to learn about transonic/supersonic
flight hands-on. Engine target 500 N. Mission: wheeled take-off from standstill, accelerate
and climb to Mach 1, hold Mach 1 for 7 s, descend and land; fly the same sortie a second
time on the same day. Airframe drag is not yet known, so the study is run "engine first"
and the airframe gets a drag budget it must meet in Phase 2.

Scripts: `scripts/phase1_requirements/` (all pyCycle runs use the placeholder cycle of
`prelim_turbojet_model.py`: OPR 4, T4 1150 K, eta_c 0.78, eta_t 0.85, convergent nozzle,
scaled NPSS maps. Phase 3 replaces these; the conclusions below are about *ratios* and
*trends*, which are far less sensitive to those placeholders than absolute values.)

## 1. The physics that drives everything: thrust lapse at Mach 1

At Mach 1 the inlet total temperature is 1.2 x ambient. At a fixed mechanical speed limit
this lowers the compressor corrected speed by ~9.5 %, and thrust falls with it. The ECU of
every real micro-turbojet limits RPM first and EGT second, so the realistic thrust
available is the *lower* of the RPM-limited and T4-limited values. pyCycle sweep,
500 N SLS-rated engine, max throttle (`data/phase1_thrust_available.csv`,
`plots/phase1_thrust_lapse.png`):

| Mach 1 at altitude | thrust available | binding limit | T4-limited value (needs N %) | q at Mach 1 | allowable CD*S = Fn/q |
|---|---|---|---|---|---|
| 0 km | 309 N | RPM | 545 N (104.7 %) | 70.9 kPa | 44 cm2 |
| 1 km | 325 N | RPM | 505 N (103.9 %) | 62.9 kPa | 52 cm2 |
| 3 km | 325 N | RPM | 428 N (102.7 %) | 49.1 kPa | 66 cm2 |
| 5 km | 325 N | RPM | 367 N (101.3 %) | 37.8 kPa | 86 cm2 |
| 8 km | 272 N | RPM | 279 N (100.7 %) | 24.9 kPa | 109 cm2 |
| 10 km | 226 N | RPM | n/a | 18.5 kPa | 122 cm2 |

**Finding F1.1:** an engine *rated* 500 N at SLS delivers only ~310-325 N at Mach 1 below
5 km. The 500 N the mission actually needs is the thrust at the dash, not the static rating.

**Finding F1.2:** the drag-area budget the airframe may have (CD*S = Fn/q) grows with dash
altitude because q falls faster than thrust: 44 cm2 at sea level vs 86 cm2 at 5 km for the
same engine. For scale, a 150 mm engine has a frontal area of 177 cm2; a well-faired body
at Mach 1 has a frontal-area drag coefficient of ~0.2-0.3 (Hoerner, *Fluid-Dynamic Drag*,
ch. 16-17, slender bodies of revolution at M ~ 1), i.e. 35-55 cm2 for the fuselage alone
before wings, tails, inlet spillage and interference. A sea-level Mach 1 dash on a 500 N
SLS engine is therefore not credible; altitude and re-defining the rating point are needed.

## 2. Decision D1.1 — operating-point definition of "500 N"

Two definitions were run like-for-like (`prelim_design_point_options.py`,
`data/phase1_design_point_options.csv`):

| definition | design airflow | thrust at SLS | thrust at M1 / 0 km | M1 / 3 km | M1 / 5 km |
|---|---|---|---|---|---|
| A: 500 N at SLS (data-sheet convention) | 0.865 kg/s | 500 N | 309 N | 325 N | 325 N |
| B: 500 N at M1 / 3 km (cycle design point there) | 1.183 kg/s | 562 N | 548 N | 500 N | 383 N* |
| B: 500 N at M1 / 5 km (cycle design point there) | 1.120 kg/s | 665 N | 548 N | 523 N | 500 N |

(*3-km-designed engine at 5 km is RPM-limited at 383 N.)

**Chosen: definition B — 500 N = uninstalled net thrust at the Mach 1 dash point, ISA,
with the compressor at 100 % corrected speed and T4 at its maximum there (that point is the
cycle design point).** SLS thrust becomes a derived output (~665 N for a 5 km dash).

Why: the user's stated purpose of the thrust is to overcome drag at Mach 1. Under
definition A the mission point gets only 65 % of the rating and the airframe budget is
44-86 cm2; under B it gets the full 500 N and 88-132 cm2. The cost is a ~30 % larger
airflow engine (1.12 vs 0.87 kg/s), which is a mass penalty Phase 2/4 must absorb inside
25 kg. That trade is explicit rather than hidden in a rating convention.

## 3. Decision D1.2 — mission profile: candidates and selection

Four dash altitudes were integrated with a point-mass energy model
(`prelim_mission_energy.py`) using the definition-B engine table
(`data/phase1_thrust_available_dash5km.csv`). The airframe drag is parameterised as 75 %
of the thrust-limited CD*S at the dash (assumption A1.2) with a transonic drag-rise factor
of 2 (A1.3). Profile: level acceleration at 300 m to M 0.7, constant-Mach climb, level
acceleration to M 1.0, 7 s hold, idle descent, 2 min idle reserve.

| candidate | dash alt | Fn at M1 | q at M1 | CD*S budget | time to M1 | sortie time | ground track | fuel incl. reserve | P3 at dash | Re index at dash |
|---|---|---|---|---|---|---|---|---|---|---|
| A | 1 km | 551 N | 62.9 kPa | 88 cm2 | 18 s | 60 s | 6.3 km | 0.82 kg | 558 kPa | 1.36 |
| B | 3 km | 523 N | 49.1 kPa | 107 cm2 | 24 s | 166 s | 7.5 km | 1.10 kg | 475 kPa | 1.12 |
| **C** | **5 km** | **500 N** | **37.8 kPa** | **132 cm2** | **31 s** | **273 s** | **9.1 km** | **1.40 kg** | **401 kPa** | **0.92** |
| D | 10 km | 289 N | 18.5 kPa | 156 cm2 | 61 s | 553 s | 15.5 km | 2.09 kg | 216 kPa | 0.53 |

(Re index = compressor-inlet Reynolds number relative to SLS static; P3 = compressor
delivery pressure at the dash, relevant to combustor stability.)

Sensitivity (`data/phase1_mission_sensitivity_dash5km.csv`): across drag margin 0.6-0.9 and
drag-rise factor 1.5-3.0, total fuel stays within 0.7-0.9 kg (A), 1.0-1.3 kg (B),
1.2-1.6 kg (C), 1.8-2.4 kg (D). Fuel is never the discriminator: every candidate needs
under 10 % of MTOW.

**Chosen: candidate C, Mach 1 dash at 5 km ISA.** Rationale with numbers:
- Drag budget is the binding constraint of this whole project (F1.2). C gives 132 cm2,
  24 % more than B and 50 % more than A, for +0.3 kg fuel over B.
- Structural/aeroelastic load at the dash is q = 37.8 kPa, 40 % below A. This matters for
  a hobby-built airframe (flutter and skin loads scale with q).
- The engine stays in a benign regime: P3 401 kPa and Re index 0.92. Candidate D drops to
  216 kPa and 0.53, where micro-turbojet combustors and small blades lose efficiency and
  stability margin (documented in small-engine altitude testing, e.g. NASA/TM small-engine
  studies; to be quantified with Cantera loading checks in Phase 3 if D is ever revisited).
- D also needs 60 s and 15 km just to reach Mach 1 and a 9-minute sortie; C is under 5 min.
- Fallback: if practical or regulatory reasons force a lower dash, candidate B (3 km) is
  the documented fallback with a 107 cm2 budget; the same engine covers it (523 N there).

## 4. Derived requirements handed to Phases 2-4

Engine (Phase 3/4):
- E1: Fn = 500 N uninstalled at M 1.0, 5000 m ISA (T2 = 306.8 K, P2 = 100.2 kPa with 0.98
  recovery), at 100 % N and T4max simultaneously. Placeholder cycle implies ~1.12 kg/s.
- E2: mechanical speed margin: the T4-limited RPM at M1 / 1 km is 102.2 % of design speed
  and 106.5 % static at 5 km (table). The ECU limit (100 %) governs; Phase 4 rotor stress
  must cover 105 % overspeed transients.
- E3: derived SLS thrust ~665 N (RPM-limited) — drives take-off ground roll in Phase 2
  and must be checked against the engine-mass database (rating used by vendors).
- E4: operating envelope: 0-6 km, M 0-1.05, ISA-15 to ISA+20 (hot-day check in Phase 3).
- E5: fuel flow at the dash ~0.019 kg/s; sortie fuel ~1.4 kg (+ reserve) -> tank 2.0 kg
  Jet-A/kerosene placeholder until Phase 2 closes the budget.
- E6: life: 2 sorties/day without inspection is the stated need; design assumption
  A1.6 = at least 10 hot cycles / 1 h at max rating before overhaul, to cover test flights.
- E7: convergent nozzle, NPR at the dash ~3.4 (choked, under-expanded). A C-D nozzle is a
  Phase 3 trade item (thrust gain vs mass).

Airframe (Phase 2):
- A1: MTOW <= 25 kg; take-off from a paved runway, wheeled landing (gear mass, stall speed).
- A2: **drag-area budget CD*S <= 132 cm2 at M 1.0, 5 km**, with 25 % of thrust reserved
  for acceleration through the drag rise (i.e. target CD*S <= 99 cm2). This is the
  requirement Phase 2 must demonstrate with a cited transonic drag build-up (Raymer /
  Hoerner / DATCOM methods), since no tool in the survey does transonic drag.
- A3: q_max = 38 kPa design dynamic pressure (dash), q at low-altitude acceleration up to
  ~45 kPa at M 0.8 / 300 m — structural design condition.
- A4: energy height 10.2 km; sortie ~4.5 min; ground track ~9 km + return — implies an
  autopilot with telemetry (not visually flyable) and airspace authorization.
- A5: fuel 2.0 kg + engine (from database) + structure + systems <= 25 kg (Phase 2 budget).

## 5. Assumptions register (Phase 1)

| id | assumption | status |
|---|---|---|
| A0.1 (superseded by D1.1) | 500 N at SLS | replaced: 500 N at M1 / 5 km |
| A1.1 | ISA standard day for all sizing; hot day checked in Phase 3 | user to confirm |
| A1.2 | airframe CD*S at the dash = 75 % of thrust-limited value (25 % acceleration margin) | design choice, revisited in Phase 2 |
| A1.3 | transonic drag-rise factor 2.0 between M 0.8 and 1.0 | placeholder; Phase 2 drag build-up replaces |
| A1.4 | idle fuel flow = 10 % of max SLS fuel flow | typical micro-turbojet ECU idle (~35-40 % RPM); Phase 3 off-design replaces |
| A1.5 | reserve = 2 min idle | design choice |
| A1.6 | engine life >= 10 hot cycles / 1 h at max rating | assumption, covers test flying before the two "real" sorties |
| A1.7 | runway: paved, >= 300 m, sea level | user to confirm (drives Phase 2 take-off constraint) |
| A1.8 | Jet-A / kerosene with turbine oil mix, as per micro-turbojet practice | user to confirm |
| A1.9 | refuelling between the two sorties is allowed; tank sized for one sortie + reserve | user to confirm |
| A1.10 | ground roll not integrated in Phase 1 (starts airborne at 40 m/s, 300 m) | Phase 2 |

## 6. Non-engineering prerequisites (stated once, not designed here)

A Mach 1 flight by an uncrewed 25 kg aircraft at 5 km altitude requires airspace
authorization and a range with telemetry/flight-termination provisions in every
jurisdiction. This does not change the engineering, but it is a hard prerequisite to
flying the mission and should be checked early by the user.

## 7. Items the user may adjust (non-blocking)

1. Dash altitude: 5 km chosen; 3 km fallback quantified. Lower than 3 km makes the drag
   budget unlikely to close (F1.2).
2. Runway length / launch site elevation (A1.7).
3. Whether a C-D nozzle or an afterburner-free design is acceptable (assumed: no reheat).

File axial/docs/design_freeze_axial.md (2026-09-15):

# Design freeze, axial option (Phase 5A): status snapshot for review (2026-09-14)

**What this document is.** The Phase 5 snapshot of the **pure axial engine** (6-stage axial compressor, OPR 5,
80 000 rpm, tag `ax80000_opr5_t1150_n6_cap_3r`), compiled from `axial/docs/phase4a_axial.md` for the user's review. The user
asked for the early 6-stage axial concept to be finished "as you did with the centrifugal one", and chose to pause here
for review before any axial CAD (brief rule 4).

* **It does not claim the design is closed.** Section 4 states the open items with their current status. Several of
  them decide whether this engine is workable at all.
* **It does not replace the centrifugal baseline.** The current baseline is still the centrifugal
  (`docs/design_freeze.md`, Phase 6 started on it). Which of the two goes forward is a decision for the reviewer
  (section 6), and section 7 compares them.
* Every number comes from a tool run or a cited relation (sources: `axial/docs/phase4a_axial.md`, `design_log.md` F3A.1-D4A.4).
  Nothing has been measured on hardware. Numbers are **fielded** (η_c 0.709, η_t 0.75, η_b 0.95) unless marked "tool".
* **Every compressor efficiency, off-design and operability number rests on the project's own axial stage-stacking
  model, which is not validated at this scale (R4.1, section 4.1).**

---

## 1. Final architecture

Single-spool turbojet: 6-stage axial compressor with a variable inlet guide vane, an overboard bleed after stage 3,
annular combustor, single-stage axial turbine, and a variable-area convergent nozzle, in the Phase 2 nose-pitot
fuselage.

### 1.1 Cycle (design point: Fn 500 N at M 1.02 / 5000 m ISA, T4 1150 K)

| quantity | fielded |
|---|---|
| net thrust / T4 | 500 N / 1150 K |
| compressor pressure ratio | 5.0 (overall 4.85 including the 3.0 % intake-duct loss) |
| airflow | 1.360 kg/s |
| fuel flow / TSFC | 22.0 g/s / 0.159 kg/(N h) |
| compressor inlet / exit | 309 K, 102.1 kPa / 559 K, 511 kPa |
| turbine inlet / exit | 1150 K, 485 kPa / 937 K, 151 kPa |
| turbine pressure ratio | 3.20 |
| nozzle | convergent, A8 70.2 cm² at design (variable to 2.0 ×), NPR 2.80, Vj 556 m/s |
| sea-level static maximum | 659 N at 98.7 % speed, limited by T4 |

### 1.2 Compressor: 6-stage axial

| item | value |
|---|---|
| spool speed | 80 000 rpm; MCS (105 %) 84 000 rpm |
| blading | TurboDesigner, sized at the fielded cycle; hub/tip 0.40, Cx 200 m/s; rotors 14/17/21/26/30/35, stators 14/18/22/26/32/36 (291 blades); Ti-6Al-4V |
| size | casing 110.3 mm; rotor-1 tip radius 52.4 mm; length 196 mm; last blade 11.8 mm |
| loading | rotor-1 tip M_rel 1.27 (limit 1.35); worst DF 0.46; de Haller 0.72 |
| efficiency | tool (Howell) 0.832; fielded 0.709 (A3A.1: same debit as the centrifugal) |
| blade roots at MCS | stages 1-2: **598 / 597 MPa = 96 % of Fty 620 MPa**, with a provisional 10 % thickness taper (Kt 1.4); stages 3-6: 523-550 MPa |
| discs | re-sized to 365 MPa at design speed: burst ratio 1.20 at MCS |
| surge margin (stacking peak-line surrogate, unvalidated) | 13.9 % at dash, 10.5 % at SLS maximum |

### 1.3 Variable geometry (option A)

| system | schedule | raw mass |
|---|---|---|
| VIGV | on corrected speed (design inlet = 100 %): design swirl 22.4° at ≥ 95 %, closing linearly by 15° at 60 % (28.7° at SLS idle) | 0.165 kg (vanes, spindles, levers, unison ring, 75 g servo) |
| overboard bleed after stage 3 | 10 % of inlet flow, open at ≤ 95 % speed | 0.122 kg (manifold, band valve, 75 g servo) |
| variable nozzle | 1.0 × A8 at ≥ 95 %, opening linearly to 2.0 × by 80 % speed | 0.354 kg (flaps, sync ring, hinges, heat-shielded 75 g servo) |

The masses are geometric estimates with hobby-class servos, **not sourced from a fielded design** (section 4.4).

### 1.4 Turbine, combustor, rotor, envelope

| item | value |
|---|---|
| turbine | single-stage axial, IN-713LC; hub 34.4 / **tip 57.3 mm, exactly on the 350 MPa blade-root limit** (A3.2); chord 11.5 mm; ~33 NGV / ~27 rotor blades; tool η_tt 0.917 |
| combustor | annular, casing OD 142.5 mm (sets the engine diameter), liner 157 mm (Phase 3 rule), reference velocity 29.8 m/s; η_b 0.95 and dP/P 0.05 assumed |
| rotor | layout A: Ti drum 2 mm, AISI 4340 shaft 24 / 12 mm, 12 mm journals (DN 1.01e6 at MCS), two hybrid ball bearings on damped soft supports (k 1.75e6 N/m, c 876 N s/m); rotor 1.60 kg, Ip 8.0e-4 kg m² |
| **engine envelope** | **OD 142.5 mm** (combustor; compressor 110, turbine 119) × **length 599 mm** |
| **engine dry mass** | **6.86 kg** calibrated (bottom-up 5.71 kg × 1.20; range 6.50-7.22 kg); accessories carried separately, 1.60 kg (A3.7) |

Largest raw mass items (kg): shaft 0.95; fasteners / seals / balancing 0.52; outer casing 0.46; compressor casing 0.46;
combustor liners 0.42; shaft tunnel and bearing housings 0.37; variable nozzle 0.35; compressor discs 0.28; drum 0.26.

---

## 2. Airframe closure (S 0.30 m², Phase 2 airframe; `ax_closure.py`, `axial/data/phase4ax/closure_<tag>.json`)

Fuel comes from the Phase 2 sortie flown on the engine's own deck (stacking compressor map with the VIGV schedule,
TurboFlow turbine map, T4-limited maximum throttle). TOGW is iterated on that fuel. **Two descent concepts are shown,
because the one the centrifugal was flown with is not physically possible for this engine** (section 4.2).

| | powered idle descent (as the centrifugal) | engine-off descent (glide, dead-stick landing) |
|---|---|---|
| fuel (incl. 120 s reserve at idle, 3 % unusable) | 5.46 kg | 1.88 kg |
| **TOGW** | **22.12 kg** | **18.54 kg** |
| **margin to 25 kg** | **2.88 kg** | **6.46 kg** |

| performance check | nominal wave drag | pessimistic wave drag |
|---|---|---|
| **dash thrust margin at M 1.02 / 5 km** (target 25 %) | **+103 %** | **+88 %** |
| brake release to M 1.02 at 5 km | 29.1 s | 29.2 s |
| 3 g sustained turn at M 0.9 / 5 km, excess thrust | +292 N | +292 N |

* **Worst corner** (η_c 0.66, combustor +1σ, pessimistic drag): +71 % in Phase 3A-R, before the Phase 4A engine
  changes (diameter and cycle unchanged, mass +1.84 kg). Not re-run.
* Take-off ground roll 54 m (V_LOF 51 m/s). Landing 177 m with flaps and the 0.6 m drag chute (300 m runway assumed,
  A1.7), in the powered-descent case.
* Of the 5.46 kg fuel in the powered-descent case, about 4.5 kg is burned at idle (descent, pattern, reserve), because
  idle fuel flow is 41 % of maximum.
* Dash hold: ~245 N (throttle 49 %) at 90 % speed, SM 12 %, bleed closed.

---

## 3. Rotor dynamics (`ax_rotor.py`, verified ROSS model)

**Result: API 684 separation criteria met** (operating range idle 77.5 % to MCS 105 %, i.e. 62.0-84.0 krpm):

| critical | amplification factor | position | requirement |
|---|---|---|---|
| 2.8 krpm | 0.56 | far below idle | none (AF < 2.5) |
| 12.4 krpm | 2.04 | below idle, critically damped | none |
| 19.6 krpm | 1.28 | below idle, critically damped | none |
| 39.9 krpm | 1.18 | 36 % below idle, critically damped | none |
| **122.3 krpm** | 5.88 | **46 % above MCS** | 23.9 % |

**What it took.** The Phase 3 mass-sized rotor passed at only 2 of 6 support settings: its bending mode (57-61 krpm,
71-77 % speed) sits just below idle. The stiffened rotor (2 mm drum, 24 / 12 mm shaft, 12 mm journals) passes at all
24 settings of the sweep, for +0.50 kg of rotor (1.10 → 1.60 kg). Unlike the centrifugal, the axial's pass does not
hang on a few millimetres of bearing span: the combustor was not shortened and the bending critical is 46 % above MCS.

---

## 4. Open risks (current status; none of these is resolved)

### 4.1 The axial compressor model is unvalidated at this scale (R4.1). OPEN, top risk.
* Efficiency, off-design loss, Howell stall and the peak-line surge surrogate come from the project's own
  stage-stacking model. It is verified against its own equations and reproduces the Phase 3 design point, but **no
  micro-scale multistage axial has been used to test it**.
* The only external check (NASA-CR-134827) supports its tip-clearance efficiency sensitivity (1.8 vs 2.0 points per 1 %
  of blade height). The same test shows clearance cutting the stall margin 12.8 → 8.7 %, **an effect the model does
  not have**.
* The peak-line surge surrogate failed by an order of magnitude on the one real stage it was checked against (a
  vaned-diffuser centrifugal, NASA HECC). It has no axial validation.
* The fielded loss split (section 5 of the report) is a modelling choice made to avoid an unphysical choke. It sets the
  shape of every speed line below design.
* **Everything in 4.2 to 4.5 inherits this.** The idle speed could be better or worse than 77.5 % on a real machine.
* **Mitigation available but not run:** a part-speed benchmark on NACA TR-758 (8-stage axial, 1943, stage-by-stage
  data; needs its geometry rebuilt and scanned figures digitised; large, subsonic and lightly loaded, so it would test
  the multistage matching logic, not micro-scale losses). Micro-scale validation needs a rig test.

### 4.2 Idle at 77.5 % speed, and the descent concept it forces. OPEN.
* Even with all three variable-geometry systems, the lowest acceptable steady speed at SLS is **77.5 %** (stator-1 stall
  below it). Idle thrust is **114 N**, idle fuel **10.0 g/s, 41 % of maximum** (the centrifugal: ~19 %; fielded
  micro-turbojets: 14-18 %).
* Idle thrust is **5-6 × the approach drag** (15-21 N). **The aircraft cannot descend or approach at idle.**
* The closure therefore needs **an engine-off descent** (shut down at the top of descent, glide from 5 km at L/D 7-9,
  dead-stick landing with flaps and the chute), or a thrust spoiler / reverser / large airbrake (not assessed).
* **Not assessed for the engine-off concept:** in-flight relight or restart (no windmill / starter analysis), a
  go-around capability (there is none without a relight), the rules' acceptance of a dead-stick landing, and the
  landing distance for a glide approach with no power.
* Relaxing the surge-margin criterion to 5 % does not lower the idle (stator 1 binds).

### 4.3 Start. NOT ANALYSED. OPEN.
* Below 70 % speed at SLS the model finds no converged steady point with the adopted geometry, and the front rows are
  beyond their Howell stalling deflection below 75 %. A start has to carry the rotor through that region.
* The starter is the centrifugal's 0.18 kg allowance. **Its adequacy for this duty (torque and power to well above
  half speed through a stalled front stage) has not been computed**, and the project has no start or rotating-stall
  model.

### 4.4 Variable-geometry hardware is unsourced. OPEN.
* Masses are geometric estimates plus three 75 g hobby-class servos (0.64 kg raw in total).
* **Not checked:** actuator loads (VIGV aerodynamic and friction torque, nozzle flap loads at NPR 2.8), a servo next to
  a 937 K exhaust, the ECU scheduling and failure modes (e.g. the nozzle stuck open costs thrust, the bleed stuck
  closed puts the engine into stall below 95 %), the bleed discharge path through the airframe.
* No fielded micro-turbojet with this variable geometry was found to anchor it.

### 4.5 Throttling at the dash condition. OPEN.
* At M 1.02 / 5 km with the bleed closed, the engine is acceptable only down to 87.5 % speed (184 N); rotor 1 stalls
  below. The dash hold (~245 N) is inside that range.
* Anything lower (a deceleration, descent from the dash, a thrust cut) needs the bleed open at altitude, which was not
  analysed.

### 4.6 Blade roots at 96 % of yield and five low-order resonances. OPEN.
* Stage 1 and 2 roots: 598 / 597 MPa at MCS against Fty 620 MPa, **only with a provisional 10 % thickness taper**. No
  margin for low-cycle fatigue (start-stop), foreign-object damage or tolerances.
* Blade 1F crossings: stage 1 × 2E at 61 %, **stage 2 × 2E at 79 %** and **stage 5 × 3E at 76 %** (both at idle, where
  the engine dwells), stage 4 × 3E at 60 %, **stage 6 × 3E at 95 %** (near maximum). No forced response, damping or
  inlet-distortion estimate; no retuning done.

### 4.7 Acceleration and transient margin: computed, quasi-steady only. OPEN.
* Idle 77.5 % → 98.5 % at SLS: **1.7 s** with a 5 % surge-margin reserve, **2.2 s** with 10 % (`ax_transient.py`).
  It is fast because the rotor is light (Ip 8.1e-4 kg m²) and the engine never crosses the low-speed range.
* At idle with a 10 % reserve only **2.2 kW** of excess power is usable: the steady margin there is 11.9 %.
* **Assumed, not shown:** the three variable-geometry systems follow their speed schedules instantly (actuator rates
  unknown, 4.4); the bleed closing at 95 % is a step whose transient is not modelled; no fuel-control, heat-soak or
  combustor dynamics. The reserves are measured against the unvalidated surge surrogate (4.1).
* Deceleration (the running line moving toward choke and the front stages toward stall as speed falls) is not
  analysed.

### 4.8 Nothing has been validated by a rig or bench test. OPEN.
Every number in this document is tool-predicted: cycle, efficiencies (fielded level borrowed from the centrifugal
debit), maps and operability, stresses, rotor dynamics, mass (calibrated on two centrifugal engines), mission.

### 4.9 Other open items (carried)
| item | status |
|---|---|
| **turbine on its 350 MPa blade-root limit** | conceptual allowable (A3.2); IN-713LC life data needed |
| **damped bearing supports** | cartridge design, temperature, nonlinearity not modelled |
| bearing DN 1.01e6 at MCS | at the 1e6 micro-gas-turbine reference |
| **mass calibration ×1.20** | anchored on two **centrifugal** engines (JetCat P400, AMT Nike); no axial micro-turbojet exists to check it, and the axial has 291 blades plus variable geometry |
| fielded technology level η_c 0.709 | borrowed from the centrifugal debit (A3A.1); the axial has no efficiency data of its own |
| worst-corner thrust margin | +71 % in Phase 3A-R; not re-run on the Phase 4A engine |
| engine length 599 mm | 41 % longer than the centrifugal (426 mm); the airframe was not re-laid out for it (Phase 2 fuselage assumed to accommodate it; installation not checked) |
| combustor | Phase 3 length rule (liner 157 mm), not re-checked; η_b and dP/P assumed |
| drag chute | required for a 300 m runway |

---

## 5. What Phase 6 (CAD / 3D) would start from if approved now

**Geometry that would be committed:** the section 1 design:
* compressor: 6 stages, 110 mm casing, 291 blades with the tapered stage-1/2 roots, drum rotor;
* VIGV, bleed manifold after stage 3 with band valve, variable nozzle;
* combustor OD 142.5 mm, liner 157 mm; turbine tip 57.3 mm;
* rotor: 2 mm drum, 24 / 12 mm shaft, 12 mm journals, damped mounts;
* envelope 142.5 × 599 mm.

**Proceeding to CAD before 4.1-4.4 are resolved means committing geometry that may have to change.** In particular:
* the **compressor blading** depends on the unvalidated model (4.1) and on the root and resonance fixes (4.6), which
  may change chords, counts and thickness in stages 1, 2, 5 and 6;
* the **variable-geometry hardware** has no sourced design (4.4); CAD would be inventing the actuation;
* the **descent concept** (4.2) changes the airframe (no change for an engine-off descent; spoilers or a reverser if
  not), and the fuel tank volume (1.88 vs 5.46 kg of fuel).

The parts least likely to change: the cycle point, the 142.5 mm diameter (set by the combustor), the turbine, and the
rotor-dynamic layout, which passes with margin.

---

## 6. Decisions for the reviewer

1. **Which engine goes forward:** the centrifugal baseline (Phase 6 already started) or this axial. Section 7 compares
   them.
2. **If the axial:** accept the engine-off descent concept (4.2) with its relight / go-around gap, or ask for a
   spoiler / reverser assessment.
3. **R4.1:** run the NACA TR-758 multistage benchmark of the stacking model (partial check, section 4.1), or accept the
   model to a rig test.
4. **Like-for-like comparison:** fly the centrifugal with the engine-off descent as well (its closure would then fall
   below 20.09 kg), so the two TOGWs compare on the same mission. Not run.
5. **Axial Phase 6:** **not started.** Approve, defer until 2-3 are resolved, or approve with the blading and the
   variable geometry explicitly held as provisional.

| | |
|---|---|
| Reviewer sign-off (Phase 5A → axial Phase 6) | not given |
| Date | |

---

## 7. Centrifugal (`docs/design_freeze.md`) against axial (this document)

Both at the fielded level, same brief, same airframe model, same calibrations.

| | centrifugal (baseline) | axial (option A) |
|---|---|---|
| compressor | 1 stage, 12 + 12 blades, OPR 4, 75 000 rpm | 6 stages, 291 blades, OPR 5, 80 000 rpm |
| variable geometry | none | VIGV + bleed + variable nozzle (3 actuators) |
| airflow / TSFC at dash | 1.326 kg/s / 0.164 kg/(N h) | 1.360 kg/s / 0.159 kg/(N h) |
| engine OD × length | **187** × 426 mm | **142.5** × 599 mm |
| engine dry mass (calibrated) | 6.85 kg | 6.86 kg |
| SLS maximum thrust | 631 N | 659 N |
| **dash thrust margin, nominal / pessimistic** | +55 / +29 % | **+103 / +88 %** |
| worst corner | +21.8 % (below the 25 % target) | +71 % |
| **SLS idle speed / thrust / fuel** | **~40 %** / - / ~19 % of max | 77.5 % / 114 N / 41 % of max |
| descent at idle | possible | **not possible** (idle thrust 5-6 × approach drag) |
| TOGW / margin | 20.09 / 4.91 kg (powered descent) | 22.12 / 2.88 kg (powered descent, not physically possible); 18.54 / 6.46 kg (engine-off descent) |
| acceleration (SLS, SM ≥ 5 % reserve) | 40 → 95 %: 6.6 s (cannot leave 40 % with a 10 % reserve) | 77.5 → 98.5 %: 1.7 s (2.2 s with 10 %); VG assumed instant |
| rotor dynamics | API pass, sensitive to ~11 mm of bearing span | API pass with 46 % margin on the bending mode |
| highest-stressed blade | impeller exducer at Fty at MCS by construction | stage-1/2 roots at 96 % of Fty (provisional taper) |
| blade resonance | exducer 1 × 19-vane passing at 39 % (idle) | 5 low-order 1F crossings, incl. at idle and 95 % |
| surge-margin prediction | unvalidated (surrogate failed on HECC; two tools disagree 28 vs 6.5 %) | unvalidated (own model, R4.1) |
| start | conventional (idle ~40 %) | not analysed (4.3) |
| hardware anchors for the architecture | 9 fielded micro-turbojets of the same type | none at this size |

**In short.** The axial trades a far better dash margin and a 44 mm smaller diameter for:
* an engine that cannot idle low enough to descend;
* three actuated systems with no sourced hardware;
* a longer engine;
* a compressor model with no micro-scale validation.

The centrifugal trades a thinner dash margin (worst corner below target) for an architecture with fielded precedent,
and a surge-margin question it shares with the axial in a different form.

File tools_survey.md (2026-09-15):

# Phase 0 — Tool survey (2026-09-13)

Platform: Windows 11, Python 3.12.10 (uv-managed venvs). The machine default is Python
3.14.3; it was **not** used because Cantera's wheel metadata caps at `<3.15` and several
candidates (OpenMDAO, CoolProp, turboflow `<4.0,>=3.11`) have no proven 3.14 support.
3.12 was the newest interpreter with wheels for every candidate. The 3.12 build on this
machine has no `tkinter`, which surfaced one packaging bug (see turbo-design).

Every status below is from an actual install + import + functional run in this session.
Smoke-test scripts: `scripts/phase0_tools/smoke_*.py`. Frozen envs: `requirements-np2.txt`,
`requirements-np1.txt`.

## 1. Summary table

| Candidate (brief name) | What it actually is | Install | Functional check | Verdict / role |
|---|---|---|---|---|
| **NASA pyCycle** | `om-pycycle` 4.4.1.dev0 from `git+https://github.com/OpenMDAO/pyCycle` @ ee7e161 (2026-05-20). **The PyPI package `pycycle` 0.0.8 is an unrelated circular-import linter** (installed, identified, removed). | OK (git) | Single-spool turbojet example: design point converged (Fn 11800 lbf target met, TSFC 0.7985, W 147.3 lbm/s, OPR 13.5) plus 2 off-design points (Fn 11000 lbf, Nmech 7944 rpm). Upstream example's print viewer crashes under NumPy 2 (`only 0-dimensional arrays...`); the solver is unaffected. | **ADOPT: Phase 3 cycle tool.** Has built-in CEA chemical-equilibrium thermo (JP-7 default, Jet-A tabular option), so real-gas combustion products are native rather than an ideal-gas assumption. |
| **Cantera** | 3.2.0 (PyPI wheel) | OK | `nDodecane_Reitz.yaml` (100 species) kerosene surrogate: phi=0.30 at T3=470 K, P3=4 bar gives T_ad 1230.9 K, gamma_products 1.3065, cp 1231.7 J/kg-K. ISA air cp 1001.8, gamma 1.4015. | **ADOPT: Phase 3.** Independent check of pyCycle's CEA thermo (T4, gamma, cp at turbine entry), flame-temperature / lean-limit envelope for combustor sizing, real-gas properties for turbomachinery hand checks. |
| **ADRpy** | 0.2.6 (PyPI, last release and commit 2024-01-26; upstream dormant, single tag) | OK only under NumPy 1.26 | Under NumPy 2: fails in `twrequired_to` and `liftslope_prad` (1-element array to scalar). Under NumPy 1.26 (`.venv-np1`): full jet (bpr=0) constraint diagram runs, 5 constraints x 14 wing loadings. | **ADOPT: Phase 2**, in the NumPy-1 env. Has `JetDeck` and a bpr/throttle-ratio thrust-lapse model appropriate to a turbojet. No mass-breakdown tool inside ADRpy, so the mass budget is a scripted statistical/parametric estimate (see gaps). |
| **pyAircraftEngineFramework** | `rmalpica/pyAircraftEngineFramework` (GitHub only, 0 stars, created 2026-01, Prosperity Public License = non-commercial). 176-line `TurbojetEngine.calculate(h, Ma)`: fixed component efficiencies, NASA-7 polynomials, on-design only. | cloned, inspected | No component maps, no off-design, no engine-deck export, no airframe coupling (grep for map/deck/airframe/mission: nothing). | **REJECT.** Duplicates pyCycle at lower fidelity and provides none of the engine-deck-to-airframe coupling implied by the brief. Coupling will be our own script: pyCycle off-design deck (thrust, SFC vs Mach/alt/throttle) feeding the ADRpy/mission script. |
| **TurboMAP** | Not found. PyPI: no package. GitHub: only unrelated hits (ORB-SLAM mapping, a C# object mapper, a 3-star C# "TurboMapCalculator" from 2021). | n/a | n/a | **NOT AVAILABLE.** Compressor-map generation is covered by TurboFlow / turbo-design (below), converted into pyCycle `MapData` format by a script we write. |
| **NASA PyTurbo** | = `pyturbo-aero` 1.3.8 (PyPI; GitHub `nasa/pyturbo-aero`, 91 stars, pushed 2026-09-01). **PyPI `pyturbo` 18.7.27 is an unrelated 2018 TensorFlow/OpenCV bundle**, not installed. | OK | Imports; `pyturbo.aero.Centrif` (centrifugal impeller + splitter builder), `Airfoil2D/3D`, `passage2D`. Geometry generation only, no performance prediction. | **HOLD for Phase 6** (3D blade/passage geometry after freeze). Not used for sizing. |
| **NASA Turbo-Design** | = `turbo-design` (GitHub `nasa/turbo-design`, 94 stars, pushed 2026-09-01). PyPI 1.4.2 (2026-03) is stale: stray `from turtle import ...` lines give `ModuleNotFoundError: tkinter`. Installed **GitHub main, v1.4.3 @ 23c2b0b** instead: bug gone, adds `turbodesign.centrifugal` (inducer/impeller/vaneless/vaned diffuser, Oh loss set, Wiesner slip), `operating_map`, `shaft_match`. | OK (git) | Ran the upstream NASA HECC validation fixture (NASA/CR-2014-218114 geometry, no tuned coefficients): work factor 0.8127 vs 0.8100 measured (+0.3 %), PR_tt 4.7805 vs 4.6847 (+2.0 %), eta_poly 0.8540 vs 0.8553 (-0.2 %). Speed line: `plots/phase0_turbodesign_hecc_validation.png`. Upstream states its own limits: choke flow 7-11 % high, vaned-diffuser diffusion factor outside correlation range, constant cp inside the solve. | **ADOPT: Phase 4 primary** for centrifugal compressor and axial turbine meanline (radial-equilibrium streamline solver; Ainley-Mathieson / Kacker-Okapuu / Craig-Cox turbine losses, Lieblein/OTAC compressor losses; Cantera-backed gas). |
| **TurboFlow** | `turboflow` 0.1.18 (PyPI; GitHub `turbo-sim/TurboFlow`, 56 stars, MIT, pushed 2026-05). Pins `numpy<2`, uses CoolProp. | OK, NumPy-1 env only | Centrifugal example (0.45 kg/s, 52 krpm, 143 mm impeller, Oh losses): converged in 3.4 s, eta_tt 83.8 %, PR_tt 2.664. Axial-turbine **design optimisation** (SLSQP; specific speed and blade-jet ratio as variables): converged in 99 s, eta_ts 90.8 %, PR_ts 2.298, full geometry returned. Performance-map mode exists for both machines. | **ADOPT: Phase 4 secondary**: (a) independent cross-check of turbo-design compressor numbers with a different loss set (Oh / Zhang), (b) axial-turbine design optimisation, (c) speed-line map generation for pyCycle off-design. Its example machine is close to our scale. |
| **TurboDesigner** | `turbodesigner` 2.0.0 (PyPI; GitHub `OpenOrion/turbodesigner`, 220 stars, MIT, pushed 2026-06). | OK | 2-stage axial compressor at 0.9 kg/s, PR 3, 70 krpm: runs, mean radius 58.7 mm, inlet Mach 0.45, stage PR 1.82 / 1.65. **Takes isentropic efficiency as an input**: free-vortex velocity triangles + Johnsen-Bullock metal angles + CadQuery STEP export, no loss model. Axial compressors only. | **HOLD**: geometry/CAD generator for an *axial* compressor option only. Used in Phase 3/4 only if the axial-compressor architecture survives the trade; otherwise Phase 6. Not a performance predictor. |
| numpy / scipy / matplotlib / pandas | 2.5.3 / 1.18.1 / 3.11 / 3.0.5 (main); 1.26.4 / 1.17.1 / 3.11 / 2.3.3 (np1) | OK | n/a | free use |

## 2. Environment decision: two venvs

`openmdao 3.45.1` requires `numpy>=2`; `turbodesigner 2.0.0` requires `numpy>=2.4.3`;
`turboflow` requires `numpy<2`; `ADRpy 0.2.6` breaks under NumPy 2 in at least two
independent code paths (take-off T/W and lift slope). Patching ADRpy line by line was
tried (the first fix exposed a second failure) and abandoned as unbounded. Isolating the
two NumPy-1 tools in `.venv-np1` costs nothing: the Phase 2 (ADRpy) and Phase 4
cross-check (TurboFlow) steps exchange only tabulated numbers (CSV/JSON) with the cycle model.

| env | packages | phases |
|---|---|---|
| `.venv` (NumPy 2.5) | openmdao, om-pycycle (git), cantera, turbo-design (git), turbodesigner, pyturbo-aero | 3, 4, 6 |
| `.venv-np1` (NumPy 1.26) | ADRpy, turboflow, CoolProp | 2, 4 (cross-check) |

## 3. Gaps and fallback plans

| Gap | Why it matters | Plan |
|---|---|---|
| **No centrifugal compressor map ships with pyCycle.** Built-in maps are NPSS large-engine maps: `AXI5` (axial, PR 5.2), `HPCMap` (E3-class, PR 10.9), `LPCMap`, `FanMap`, `NCP01` (a *fan*-scale map, Wc 1100-2100 lbm/s). None is a small centrifugal characteristic. | Off-design (Phase 3) needs a map whose shape (surge line, choke, efficiency islands) matches a small backswept centrifugal stage. | Phase 4 generates a speed-line map with turbo-design `operating_map` and/or TurboFlow performance-map mode; a converter script writes it into pyCycle `MapData` (Nc, R-line, Wc, PR, eta arrays). Until then, Phase 3 on-design and first-pass off-design use pyCycle's scaled `AXI5` / `HPT1269` maps, explicitly flagged as placeholders. |
| **No tool estimates engine mass or envelope.** | Engine mass is the largest single driver of the 25 kg closure. | Two independent estimates, both logged: (1) bottom-up from Phase 4 geometry (impeller, diffuser, turbine disc, shaft, combustor liner, casing volumes x material densities, plus bearings/starter/ECU/fuel pump from vendor data sheets); (2) statistical fit of thrust vs mass and diameter for commercial micro-turbojets in the 100-1000 N class, compiled from published data sheets into `data/microturbojet_database.csv` with a source per row. Any discrepancy between (1) and (2) is reported, not averaged away. |
| **No airframe mass-breakdown tool** (ADRpy has none). | Phase 2 mass budget. | Scripted parametric breakdown for small jet UAVs (structure fraction, systems, fuel, payload) using published small-UAV weight-fraction data (Raymer Ch. 3; Gundlach, *Designing Unmanned Aircraft Systems*), cited in the log, with fuel mass from pyCycle SFC x mission integration. Sensitivities reported. |
| **Engine deck to airframe coupling** (pyAircraftEngineFramework rejected). | Mission fuel and thrust lapse across the Phase 1 profile. | Own script: pyCycle off-design runs on a (Mach, altitude, throttle) grid -> `data/engine_deck.csv` -> mission integrator feeding ADRpy weight fractions. |
| **ADRpy dormant since 2024-01.** | Risk of further NumPy/SciPy breakage. | Pinned in `requirements-np1.txt`; the constraint equations are simple enough that a from-scratch reimplementation (Raymer / Gudmundsson forms) is the fallback if it breaks. |
| **turbo-design is pre-release and under active development** (GitHub main pinned to commit 23c2b0b; PyPI stale). Upstream lists unresolved choke-flow and diffuser-loss limitations. | Phase 4 compressor numbers. | Pinned commit; every result cross-checked against TurboFlow (independent loss models) and read against the HECC validation error band (eta +-0.5 pt, PR +-2 %, choke +7-11 %). Choke margin will be taken from TurboFlow as well before trusting either. |
| **pyCycle example code is NumPy-2-fragile** (viewer/print helpers). | Cosmetic. | Our scripts read outputs with `prob.get_val()` and index `[0]`; `OPENMDAO_REPORTS=0`. |

## 4. Preliminary observation to carry into Phase 1

From the ADRpy smoke run (placeholder inputs, not a result): with generic small-jet
aerodynamics (AR 6, CDmin 0.030, 60 m ground run, 1500 fpm climb, 150 kt cruise at 1 km,
2 g turn) the constraint diagram asks for T/W of about 0.3-0.6 over W/S 150-800 Pa,
while 500 N on 25 kg is T/W = 2.04. Either the mission is far more demanding
(high-subsonic dash, steep climb, high altitude, very short launch) or the 500 N reference
point is not the rating at which the 25 kg airframe is sized. This is the load-bearing
question for Phase 1 and is flagged there rather than resolved here.

## 5. Phase 2 additions (2026-09-13)

| Tool | Status | Role |
|---|---|---|
| **AeroSandbox** 4.2.10 (`.venv`, PyPI, MIT) | installed; `approximate_CD_wave`, `critical_mach`, `fuselage_base_drag_coefficient`, `sears_haack_drag_from_volume` verified or traced to cited sources | cited transonic helper models inside our drag build-up. `sears_haack_drag(radius, length)` returns CD on frontal area although documented as drag area (39x off in the test): not used. |
| **ADRpy** 0.2.6 | two more defects found in use: default quarter-chord sweep has an operator-precedence bug (`constraintanalysis.py:392`, lift slope 1.23 instead of 2.87/rad for our wing); the sustained-turn constraint uses the climb weight fraction | both worked around (explicit `sweep_25_deg`, one concept object per constraint); results cross-checked against DATCOM and our own mission model (dash drag 361.1 vs 361.3 N) |
| own slender-body wave-drag integral (`scripts/phase2_airframe/aero_utils.py`) | verified: Sears-Haack ratio 1.0007, parabolic-area body 0.9607 = exact analytic | shaping comparisons of the area distribution |

## 6. Phase 3 additions and findings (2026-09-13)

| Tool | Finding in use | Handling |
|---|---|---|
| NASA turbo-design (axial compressor) | no usable loss model: `loss/compressor/lieblein.py` is empty, OTAC classes are zero-returning placeholders, `DiffusionLoss` is an ad-hoc ramp | not used for axial efficiency |
| TurboDesigner 2.0.0 | efficiency is an input; rotor diffusion factor computed with absolute velocities (wrong); last stator `next_flow_station` asserts | used for geometry and triangles only; DF recomputed; own Howell loss model (verified) supplies efficiency |
| TurboFlow 0.1.18 (turbine design optimisation) | ignores the operating-point omega (derives it from specific speed); no structural constraint (optimum at 688 m/s tip speed) | omega equality constraint + blade-root-stress tip-radius constraint added |
| TurboFlow 0.1.18 (centrifugal performance) | works; needs its Latin-hypercube heuristic initial guess; the design point can be choked with a 0.5 throat ratio | throat opened until unchoked |
| pyCycle | TABULAR thermo agrees with Cantera to 0.3 % on T4; fresh-start design solves can fail at high OPR / low efficiency | retry from several initial guesses |
| pypdf (added to `.venv`) | used only to read the Cranfield combustion lecture PDF for the theta-parameter definition | not part of the design chain |

## 7. Phase 4 additions (2026-09-13)

| Tool | Status | Role |
|---|---|---|
| **scikit-fem** 12.0.2 (`.venv`, PyPI, BSD-3) | installed. Own axisymmetric rotating-body FE (`scripts/phase4_turbomachinery/axisym_fe.py`) verified against the Timoshenko & Goodier rotating-disc and thermal-disc solutions to within 0.5 %. Morley plate element verified against cantilever theory (+5 %) | impeller disc stress, burst, blade-root bending (impeller stress gate) |
| pypdfium2 5.13.0 (`.venv`) | used only to render data-sheet chart pages (ATI Ti-6Al-4V) for reading | not part of the design chain |
| gap | no approved tool does 3D solid FE of a bladed rotor (rake and lean, blade modes) | out of scope for the gate. Flagged in `docs/phase4_impeller_stress_gate.md` |
| **ross-rotordynamics** 2.3.0 (`.venv`, PyPI, MIT) | installed. Verified against the simply supported shaft, the Jeffcott rotor and an overhung gyroscopic disc (errors of 0.0001-0.20 %). Needs two import work-arounds for plotly 7 and numba 0.67 (`ross_shim.py`); these do not touch the FE matrices | rotor critical speeds, Campbell diagram, damped AF (`axial/docs/phase4_rotordynamics.md`) |
| TurboFlow 0.1.18 (turbine performance analysis) | two defects: (1) with `stop_on_failure=False`, a failed point crashes the summary printer (np.mean over None); (2) every point after a failed one fails, because the failed solution is reused as the initial guess | summary disabled; each speed line swept outward from the design PR (`turbine_map.py`) |
| TurboDesigner 2.0.0 (input convention) | `physical_area = flow_area * (1 + blockage)`. **Phase 3 passed 0.98 / 0.96 (a project error, not a tool bug), which doubled every axial annulus** | corrected to 0.02 / 0.04; axial trade re-run (`docs/phase3_engine.md` section 14) |
| gap | no approved tool gives axial-compressor maps | own stage-stacking model `axial_offdesign.py` (Howell stall criterion), verified at the design point, bracketed with the NPSS AXI5 map shipped with pyCycle |

## 8. Phase 3R findings (2026-09-14)

| Tool | Finding | Handling |
|---|---|---|
| TurboFlow 0.1.18, centrifugal compressor | **defect:** `slip_model.get_slip_weisner` computes `np.sqrt(np.cos(theta_out))` with `theta_out` in degrees, while `flow_model.py` treats it as degrees (`math.tand`). The solved slip factor is 0.931 instead of 0.837 at -30 deg (+18 % PR at a given tip speed), and the model returns NaN at -10 / -40 deg. At the upstream example's -24.5 deg the error is only 6 %, so the Phase 0 smoke test did not reveal it | run-time patch `scripts/phase3_cycle/turboflow_fixes.py` (imported by `centrifugal_design.py`, `centrifugal_map.py`); evidence and verification `verify_turboflow_slip.py` (solved σ = Wiesner exactly after the patch) |
| TurboFlow 0.1.18, centrifugal loss set (Oh) | limitation: no shock loss term, so efficiency at high inducer relative Mach is not trustworthy. The impeller incidence loss uses the full inlet relative tangential velocity (literal Conrad form) | spool speed limited to the fielded inducer range (M1s,rel <= 1.33, `inducer_anchor.py`) |
| TurboFlow 0.1.18, vaned diffuser ('custom' loss) | insensitive to the diffuser radius ratio (0.0003 in η between R4/R2 1.35 and 1.45), so it cannot size the diffuser, which sets the engine diameter | R4/R2 1.35 kept; flagged for Phase 4 |
| TurboFlow 0.1.18, turbine design optimisation | returns `success=False` at feasible points (flow, speed and tip constraints met exactly) for several fielded turbines; at 85 000 rpm it cannot meet the fielded flow within the stress limit | constraints checked explicitly (`docs/phase3r_centrifugal.md` section 5) |
| pyCycle T4-limited off-design mode (speed balance) | does not converge with the TurboFlow maps | deck built in N mode with a secant search on speed for T4 = T4max (`cc_mission.py`) |
| NASA turbo-design `turbodesign.centrifugal` (GitHub main 23c2b0b) | code review (Phase 4): no degree/radian errors; Oh loss set with Aungier entrance-diffusion and head-loss corrections; splitters via Aungier Z_eff; builds a stage from meanline scalars (`flowpath_builder.build_flowpath`). Limitations: no shock loss, no surge or diffuser-stall criterion (choke raises exceptions); the vaned-diffuser loss is a Lieblein cascade correlation beyond its fitted range (no area-ratio or stall physics), so it cannot size the diffuser; the solver needs `x_le` strictly inside the path. Minor issues: the inducer choke loss uses sin where the package elsewhere uses cos (inactive on HECC); leakage uses Z_eff while clearance and mixing use Z_exit; the diffuser P0 loops can fail to converge silently | used as the independent design-point check of the Phase 3R impellers (`td_check.py`): PR within 1 %, η within 1.5 points of TurboFlow |
| **Phase 6 CAD toolchain** (separate `.venv-cad`, Python 3.12.10, NumPy 2.5.3, `requirements-cad.txt`) | **CadQuery 2.8.0 / OCCT 7.9.3 (cadquery-ocp)**, **gmsh 4.15.2**, **pyturbo-aero 1.3.8**. Verified with `scripts/phase6_cad/smoke_cad.py`: box volume exact and STEP round trip exact; B-spline surface fitted through a point grid on a cylinder patch reproduces the analytic area (+0.0000 %); loft of closed spline sections gives a valid solid of the analytic volume (+0.0000 %); gmsh tetra mesh of the STEP box sums to the exact volume. Quirks: the OCP bindings need `GeomAbs_Shape` enums, not integers; the process exits non-zero after the script completes (teardown), so do not rely on the exit code. build123d resolves too, but ships a different OCP build (novtk), so not in the same env | a separate venv so the frozen `.venv` is untouched |
| pyturbo-aero 1.3.8 `Centrif` (impeller geometry) | generates blade suction/pressure-side point clouds (cylindrical and Cartesian), splitters, full wheel and hub/shroud; **no file export or solids** (a kernel is needed). Defect: `Centrif.patterns` is a class-level list that `__init__` appends to, so every new instance adds another default pattern shared by all instances (reset it, or build one wheel per process) | geometry generator for the impeller blades in Phase 6 (used; section 9) |
| pyturbo-aero 1.3.8 `Centrif`, found building the impeller (Phase 6) | see section 9 | |
| peak-PR surge surrogate (both meanline tools) | **fails on NASA HECC** (measured): real surge at 95 % of design flow with PR still rising (design SMN 8.4 %); turbo-design's characteristic rises down to 61 % flow (surrogate >= 73 %). For vaned diffusers, surge is set by diffuser stall, which neither tool models | surge margins are unvalidated; carried as risk R4R.1 (`hecc_surge_check.py`) |

## 9. Phase 6 findings (2026-09-14): CAD and 3D FE toolchain in use

| Tool | Finding | Handling |
|---|---|---|
| pyturbo-aero 1.3.8 `Centrif`, conventions | metal angles from meridional; a backswept TE has the same sign as the LE; thickness is a half-thickness in conformal units (t/2)/r; profiles are placed at i/(n-1) of span whatever `percent_span` says; `tip_clearance` is ignored; Cartesian y = r sin θ, z = r cos θ | one profile per span row; clearance put on the casing |
| pyturbo `Centrif`, defects | (1) the first thickness station receives the LAST list value; (2) `build()` cannot be called twice; (3) `apply_camber_shifts` loops over all profiles while only i+1 cambers exist (IndexError), so LE/TE theta shifts are unusable; (4) `add_SS_Wave` indexes a function instead of calling it; (5) `get_camber_length` is missing an argument; (6) `Centrif.patterns` is class-level (section 8) | (1) last value = the thin TE; (2) one build per process; (3)-(5) not used |
| pyturbo `Centrif`, camber | a 4-point Bezier per profile; with `use_mid_wrap_angle` every span gets the mid-span TE theta. With the short shroud this hooked the camber from 43 to 15 deg in the last 10 % of chord; the throat and the TE angle cannot both be met | `__build_camber__` hooked (not name-mangled: the name ends in `__`) with a least-squares Bezier of the radial-fibre + exducer-backsweep law (14 points, end slopes exact, fit <= 0.6 deg) |
| pyturbo `Centrif`, surfaces | SS and PS are Beziers whose CONTROL points are the camber offsets (not interpolated): with the default ~10 points the surfaces smooth away from camber +- t | `camber_follow_density = 60`: CAD angles within 1.1 deg of the law along the chord |
| pyturbo `Centrif`, splitters | `splitterblade` sits at the main blade's theta; the half-pitch offset is applied only in `__create_fullwheel__`. Taken as-is, every splitter lay inside a main blade (746 of 841 mm3 overlap), and the first wheel mass counted the splitters twice | splitter rotated +15 deg in theta; overlap checked = 0 |
| pyturbo `Centrif`, LE / TE | the LE is closed by a single nose point (30-67 deg kink between the first segments) and the TE by a perpendicular offset: a coarse closure, not a designed round | stated; no aero use of the LE shape |
| OCCT 7.9 / CadQuery 2.8, faceted solids | a blade solid sewn from triangles with FAN end caps (centroid fan of a thin cambered section) passes BRepCheck and has a plausible volume, but every boolean with it returned empty | ladder caps (SS[j]-PS[j] strips); grid-integrated volume matches the solid to 0.01-0.05 % |
| OCCT booleans | (a) a revolved wedge ∩ faceted blade returned empty where a planar prism worked; (b) the `common()` result of an UNCUT faceted solid, fused with the hub, added zero volume (one test); (c) fusing 24 faceted blades with the hub took > 17 min | (a) planar / ruled-loft tools only; (b) a volume-closure check after every boolean (the sector build asserts it); (c) wheel = 12 copies of a 30 deg sector |
| gmsh 4.15.2, `setPeriodic` | needs the same face topology on both cut surfaces ("Cannot find periodic counterpart of node"); the faceted blades crossing flat cut planes did not give it | cut faces meshed independently; cyclic tie by P2 interpolation on the master face (exact for matching meshes) |
| pyamg 5.3.0 (added to `.venv-cad`) | smoothed aggregation + CG converges in ~60 iterations on matching cyclic constraints (agrees with SuperLU to 1e-7); with the interpolated tie on the twisted boundary it stalled at 5e-4 after 2000 iterations, and at 3e-2 on the flat-cut sector with blade slivers (near-singular) | direct solvers instead. SciPy SuperLU (`splu`, `MMD_AT_PLUS_A`) is fine to ~150 k dof, but committed 13.7 GB (paging) at 220 k dof on this 14 GB machine. **pypardiso 0.4.7 (MKL PARDISO 2026.1)**, added to `.venv-cad`: agrees with SuperLU to 3e-15 (test matrix) and 5e-7 (verification B'), residual ~1e-12, 2.7 s vs minutes — the production solver |
| pyCycle off-design initial guesses (`cycle_model.set_design`) | fixed seeds (W 2.0 lbm/s, FAR 0.018, turbine PR 2.0) converge for the Phase 3/4 cycles, but at η_c 0.709 (W 3.0 lbm/s) Newton diverged to NaN and left every internal state (flow stations, map R-line, turbine map PR) at garbage, even with the Phase 4 maps | `cycle_model.seed_od_from_design` (copy the design-point implicit states) + marching from the design flight condition (Phase 4A) |
| pyCycle / OpenMDAO Newton, `od_mode="NT4"` sweeps | a failed solve keeps its diverged iterate as the next starting point: a 1150 → 700 K jump in imposed T4 failed, and every later point of the run then failed too (first `ax_transient.py` run: no converged point at any speed). With the down-march from 1150 K, 77.5 % speed still gave no converged point (cause not isolated) | `ax_transient.solve` restores the last converged output vector (`model._outputs.asarray(copy=True)` / `set_val`); T4 marched in 15 K steps from the steady line, speed marched along the steady line |
| own stage-stacking model (`axial_offdesign.py`) with fielded-level losses | scaling the whole calibrated row loss by the fielded debit doubles its incidence parabola and chokes every flow below 80 % speed; and a blading sized at a set efficiency must be rebuilt at that efficiency | `fielded()`: debit as a constant extra loss, triangles at `eta_sizing` (Phase 4A); the Phase 3 regression is unchanged |
| reportlab 5.0.1 (added to `.venv-cad`) | PDF generation for the engine specification sheet. Its standard Type-1 fonts lack Greek and math symbols (η, ≥, −), so the DejaVu TTFs that ship with matplotlib are registered. Output checked page by page after rasterising with pypdfium2 (throw-away `uv run --with pypdfium2`, not installed) | `spec_sheet.py` only; no analysis depends on it |
| TurboFlow 0.1.18, impeller throat | `area_throat_ratio` multiplies the EYE area; the choke check (`evaluate_throat`) is isentropic, relative flow normal to the throat, rothalpy = h01, throat at the arithmetic-mean eye radius. Reproduced by hand: tool level 0.70 -> 1.086, 0.75 -> 1.164 x design flow, the same bracket Phase 3R found | CAD throat checked with the same formula on the fielded eye (`impeller_cad.choke_ratio`) |

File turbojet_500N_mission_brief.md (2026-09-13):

# Project: 500 N-Class Turbojet + ≤25 kg MTOW Airframe — Conceptual Design Study

## Role

You are acting as a propulsion-and-airframe conceptual design engineer running an
integrated engine/airframe sizing study. This is a **conceptual sizing and
preliminary performance/mass study** — the goal is a defensible, quantitatively
justified design freeze, not a CAD model or a detailed-stress analysis.

## Top-level requirement

- Engine thrust target: **500 N**. State and log your working assumption for the
  reference condition (e.g. sea-level static, ISA) if I haven't pinned it down —
  don't block on it, just flag the assumption clearly.
- Airframe MTOW ceiling: **≤ 25 kg**.
- The aircraft is designed *around* the engine: engine mass/size/thrust drive the
  airframe constraint sizing, but iterate — if the engine you converge on can't
  physically fit inside a 25 kg airframe, that's a finding, not a failure, and you
  should go back and re-trade the engine architecture.

## Ground rules (non-negotiable)

1. **No guessing.** Every architecture or parameter decision must be backed by a
   quantitative run from one of the tools below, or a clearly cited engineering
   source/handbook relation. If a tool can't answer a question, say so explicitly
   and propose the next-best method — don't quietly substitute a hand-waved number
   for a result a tool should be computing.
2. **Show your work.** Maintain a running `design_log.md`: for every non-trivial
   decision, record the tool used, key inputs, outputs, and *why* this option beat
   the alternatives — with numbers, not adjectives.
3. **Verify tools before trusting them.** Don't assume a library's API or install
   status from memory. Actually try to install/import each candidate tool early,
   check it does what its name implies, and flag anything abandoned, broken, or
   not a good fit — then propose an alternative rather than forcing it.
4. **Gate before CAD.** Do not start 3D modeling or move into detailed mechanical
   design until I have explicitly reviewed and approved the Phase 5 design freeze.

## Tool menu (you choose per task — justify the pick, don't default by habit)

- **NASA pyCycle** — 0D/1D thermodynamic cycle analysis (on-design + off-design)
  for the turbojet cycle: compressor/turbine work split, OPR selection, SFC, mass
  flow.
- **Cantera** — combustion chemistry and real-gas thermophysical properties to
  feed the cycle model (flame temperature limits, species, accurate cp/cv/γ)
  instead of pure ideal-gas assumptions; combustor sizing sanity checks.
- **ADRpy** — aircraft-level conceptual design: thrust-to-weight vs wing-loading
  constraint diagrams, mission sizing, and a first-pass mass breakdown to check
  the 500 N engine is compatible with a ≤25 kg airframe across the mission.
- **pyAircraftEngineFramework** — engine-deck ↔ airframe performance coupling, if
  it exists and genuinely earns its place; confirm before committing to it.
- **TurboMAP / NASA PyTurbo / NASA Turbo-Design / TurboFlow / TurboDesigner** —
  turbomachinery meanline/preliminary design and compressor/turbine map
  generation, once the cycle model has fixed mass flow, pressure ratio, and
  spool speed targets.
- Standard numpy/scipy/matplotlib/pandas — use freely for supporting calculation
  and plotting, no justification needed.

## Phased workflow

### Phase 0 — Setup & tool survey
Set up the Python environment, attempt to install/import each candidate tool,
and record what actually works, what doesn't, and your fallback plan for any
gap (e.g., a minimal ideal-cycle script if pyCycle won't install). Output:
`tools_survey.md`.

### Phase 1 — Requirements & assumptions
Pin down the operating-point definition for the 500 N target and a rough
mission profile (launch/takeoff method, cruise segment, endurance) appropriate
for a ≤25 kg jet-powered airframe. Propose 2–3 candidate mission profiles,
pick one with stated rationale, or ask me one clarifying question only if it's
truly load-bearing for everything downstream.

### Phase 2 — Aircraft-level constraint sizing (ADRpy)
Build a T/W vs W/S constraint diagram to check feasibility of a ~500 N engine
on a ≤25 kg aircraft across the mission. Output: target thrust requirement at
each mission segment, a wing area/loading range, and a first-pass mass budget
(structure/payload/fuel/engine split).

### Phase 3 — Engine cycle design & trade study (pyCycle + Cantera)
Build an on-design cycle model for the reference thrust point. Quantitatively
trade at least 2–3 architecture options (e.g. single- vs two-spool; centrifugal
vs axial compressor; OPR sweep), each with cycle SFC, mass flow, and an
estimated engine mass/size, using Cantera-derived gas properties rather than
ideal-gas assumptions at the combustor/turbine-entry conditions. Run off-design
points across the Phase 1 mission. Recommend one architecture, with the
rationale tied to the actual numbers produced.

### Phase 4 — Turbomachinery preliminary design
Using the cycle-level mass flow/pressure ratio/spool speed targets, run
meanline/preliminary compressor and turbine design with the appropriate tool.
Produce estimated component efficiencies, stage counts, and rough dimensions
and mass. Feed the mass estimate back into the Phase 2 airframe budget and
re-check the 25 kg constraint — iterate Phase 2 ↔ 4 until it closes or you can
show it can't.

### Phase 5 — Design freeze — **STOP and wait for my approval**
Compile `design_freeze.md`: final architecture, key cycle numbers,
component-level summary, mass budget closure against 25 kg, open risks, and
remaining uncertainties. **Do not proceed to Phase 6 without my sign-off.**

### Phase 6 — 3D modeling & further analysis (only after go-ahead)
Once approved, propose the CAD/3D toolchain (e.g. CadQuery/FreeCAD scripting)
and confirm it with me before generating any geometry.

## Deliverables per phase
- Scripts (not just notebooks), in a clean repo structure
- `design_log.md`, updated continuously
- Plots: constraint diagram, cycle trade-study, component maps
- `design_freeze.md` at the Phase 5 gate

Start with Phase 0.

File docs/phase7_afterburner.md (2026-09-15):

# Phase 7 — Afterburner (2026-09-15)

**What this is.** The user asked for an afterburner on the frozen centrifugal engine, and chose its
purpose and the nozzle treatment: **extend the envelope past Mach 1**, and **decide the variable
nozzle on numbers across three concepts**. This is the conceptual study of that afterburner.

**What it is not.** It is not a design freeze, it does not resolve any of the open decisions in
`docs/design_freeze.md` section 6, and it does not touch the Phase 6 CAD. The frozen engine's open
risks (surge margin 4.1, idle transient 4.2, combustor length 4.3, exducer/vane resonance 4.4, no
hardware validation 4.5) are all still open and none of them is made better by this work. Three of
them are made **worse**, and that is stated in section 10.

Every number here comes from a tool run or a cited relation. Scripts are in
`scripts/phase7_afterburner/`, data in `data/phase7/`, figures `plots/phase7_*.png`.

---

## 1. Headline

| question | answer |
|---|---|
| Does the tool support it, and is the baseline undisturbed? | Yes. `cycle_model.py` gains an `afterburner` option, **off by default**. With it off the model reproduces the frozen fielded dash point to every digit, and the real-map dry deck to 0.000 % at all ten Mach numbers. |
| What does it buy at the dash? | **+79 % net thrust**: 500 → 896 N at M 1.02 / 5 km, at Tt7 1900 K. TSFC 0.164 → 0.267 kg/(N h). |
| How far past Mach 1 does it get? | **It is not thrust-limited anywhere up to M 2.0.** The limit moves to the engine's own hot end: the **turbine exit annulus chokes at M 1.33**. The airframe's dynamic pressure doubles at M 1.41. |
| What does the nozzle have to do? | Open **54 % in area** (throat 94.9 → 119.3 mm). Without that, the afterburner buys +10 % instead of +79 % **and halves the surge margin**. |
| Which nozzle? | **Translating plug.** Its actuation load is 123 N against the iris's 1198 N — 9.7 × less — and it is the only concept for which a sourced, in-production actuator meets the load. |
| Does it still close under 25 kg? | **Yes, but only just, and only if the afterburner is used briefly.** 24.78 kg (+0.22 kg margin) for the conservative build used for the supersonic acceleration and the 7 s hold. **26.02 kg — over the limit — if it runs through the whole 27.7 s acceleration.** |
| What does it cost? | **+4.08 kg** and **+458 mm** of engine length: the engine more than doubles (426 → 810 mm raw CAD). |
| Does it draw? | Yes — `cad/engine_with_afterburner_assembly.step`, built on the Phase 6 engine with 25 of its parts carried over unchanged and 17 new ones, **42/42 solids valid**. The afterburner fits inside the engine envelope with a 10.2 mm annulus to spare; **its nozzle actuator does not fit anywhere** (section 9.1). CAD mass is +0.298 kg over the model, which puts TOGW **0.100 kg over the 25 kg ceiling**. |

---

## 2. Verification before anything else (`verify_ab_cycle.py`)

Per the brief's rule 3. All checks pass.

**0. The Rayleigh relations** added in `ab_common.py` against published Rayleigh-flow tables
(γ 1.4): Tt/Tt\* and Pt/Pt\* at M 0.2 / 0.3 / 0.5, worst error **2.1e-5 relative**.

**1. Regression — the afterburner option changes nothing when it is off.** `cycle_model` with
`afterburner=False` at the frozen fielded dash point:

| | now | frozen | error |
|---|---|---|---|
| Fn | 499.99999 N | 499.99997 N | 4.3e-8 |
| W | 1.3257543 kg/s | 1.3257543 kg/s | 1.7e-16 |
| TSFC | 0.1641596 | 0.1641596 | 4.3e-8 |
| Tt5 / Pt5 | 971.5062 K / 149.3242 kPa | same | < 3e-9 |
| A8 | 70.76905 cm² | 70.76905 cm² | 2.3e-9 |

**2. Null afterburner.** With `afterburner=True`, zero AB fuel and zero AB loss, every quantity
matches the `afterburner=False` run to ≤ 1e-9, and Tt7 = Tt5, Pt7 = Pt5 exactly. The extra station
is transparent, so any later difference is the afterburner and not the plumbing.

**3. The afterburner's own physics.**
* **Fuel bookkeeping.** pyCycle's tabular `ThermoAdd` references the mix ratio to the incoming
  **dry air**, so for a second burner in series the ratio is still per unit dry air and the
  composition accumulates. Checked, not trusted: `Wf_ab = W_air × FAR_ab` to 3.5e-16 and
  `FAR_total = FAR_main + FAR_ab` to 1.5e-16. Had this been read wrong, every TSFC here would be
  wrong.
* **Energy.** The tabular fuel carries **zero injection enthalpy** in the table's datum (the heat of
  reaction lives entirely in the FAR-dependence of *h*), which makes an internal energy balance
  vacuous — so the heat release is checked against **Cantera** instead, the same cross-check
  `phase3_cycle/cantera_check.py` runs on the main burner, extended to a second burn in the
  vitiated stream: **Cantera 1925.7 K vs pyCycle 1900.0 K, +1.35 %.** (The main burner agreed to
  −0.35 % at 1150 K; the gap widens at 1900 K where dissociation and surrogate differences matter
  more.)
* **Area.** A8 against the closed-form choked-throat relation: **+0.15 %**.
* **Thrust.** Fg against momentum + pressure, with Cv debiting the momentum term only (pyCycle
  `nozzle.py:117`): **1.2e-6**.

---
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

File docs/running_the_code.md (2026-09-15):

# Running the code

Per-phase command reference for `boomsonic_v0`. Everything runs **from the repo root**.
See [README.md](../README.md) for what the project is and what it found, and [axial/README.md](../axial/README.md) for the axial branch.

## Environments (three, on purpose)

Python 3.12.10 via `uv`. Three venvs because ADRpy and TurboFlow are NumPy-1-only while
OpenMDAO/pyCycle and turbodesigner require NumPy ≥ 2 (details in `tools_survey.md`).

```powershell
uv venv --python 3.12 .venv      ; $env:VIRTUAL_ENV="$PWD\.venv";     uv pip install -r requirements-np2.txt
uv venv --python 3.12 .venv-np1  ; $env:VIRTUAL_ENV="$PWD\.venv-np1"; uv pip install -r requirements-np1.txt
uv venv --python 3.12 .venv-cad  ; $env:VIRTUAL_ENV="$PWD\.venv-cad"; uv pip install -r requirements-cad.txt
```

| env | packages | used for |
|---|---|---|
| `.venv` | openmdao, om-pycycle (git), cantera, turbo-design (git), turbodesigner, aerosandbox, scikit-fem, ROSS | cycle, combustion, turbomachinery, drag build-up, rotor dynamics |
| `.venv-np1` | ADRpy, turboflow, CoolProp | airframe constraint sizing, centrifugal/axial meanline design and maps |
| `.venv-cad` | CadQuery 2.8 (OCCT 7.9), gmsh, pyturbo-aero, scikit-fem, meshio, pypardiso, VTK | CAD, meshing, 3D FE, rendering |

`.venv-cad` has no pip; install with `uv pip` as above. Its Python processes exit non-zero at
teardown after finishing (an OCP quirk), so check outputs, not exit codes.
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

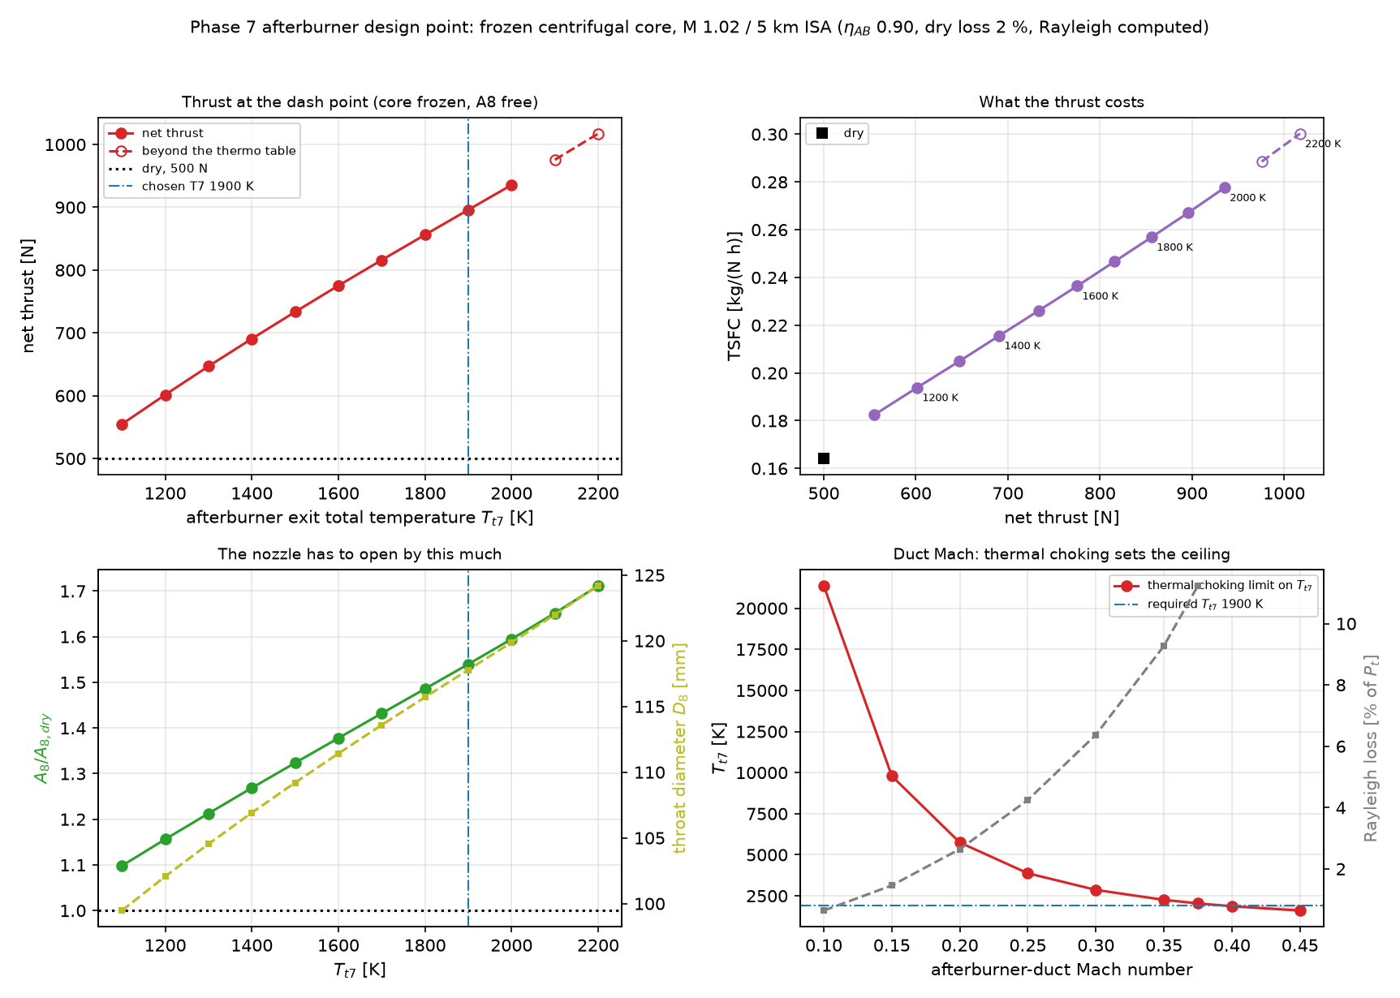
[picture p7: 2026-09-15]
plots/phase7_ab_design_point.png

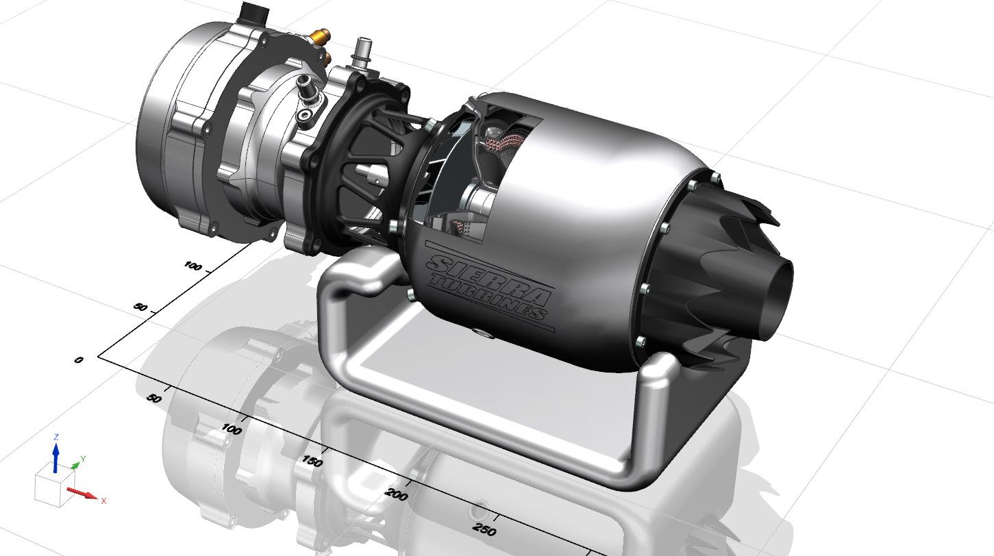
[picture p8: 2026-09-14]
Turbine-Image-1.webp

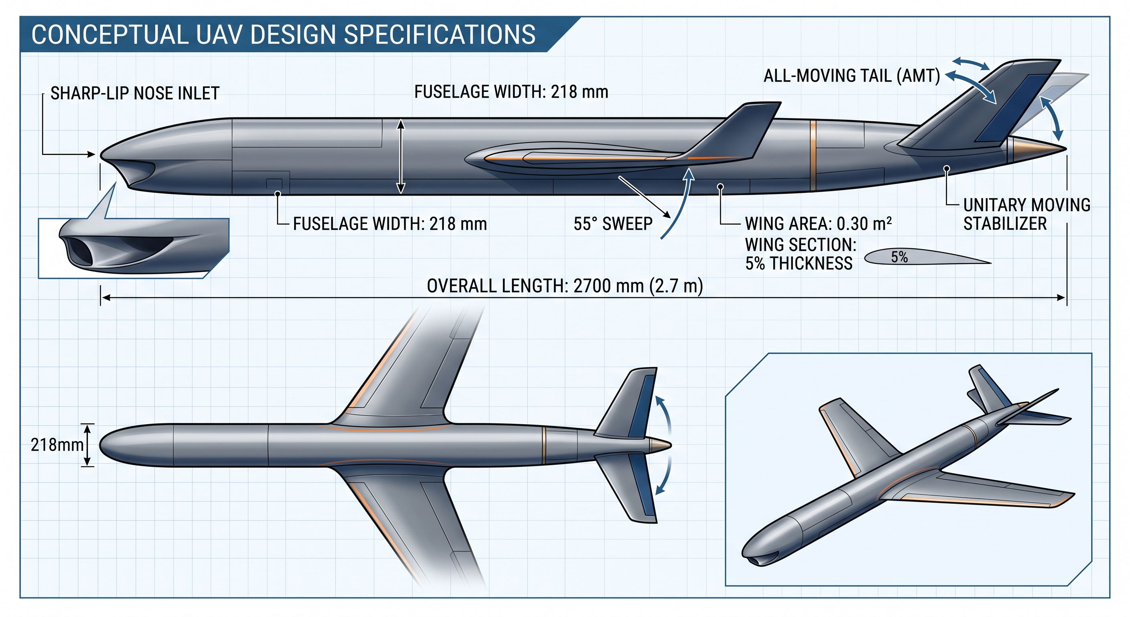
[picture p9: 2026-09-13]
Gemini_Generated_Image_e1jb56e1jb56e1jb.jpg

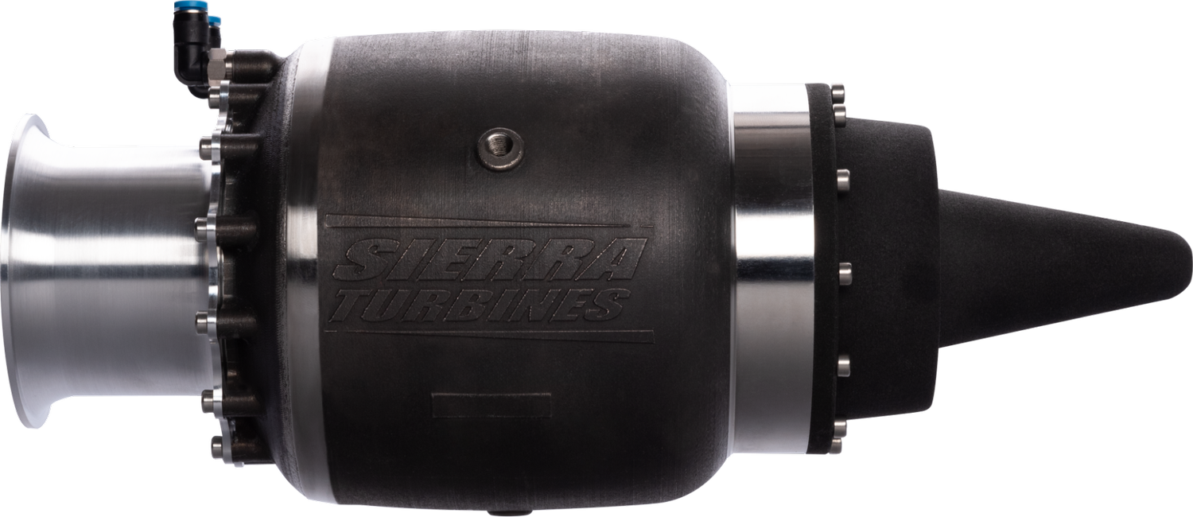
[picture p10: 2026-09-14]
float_01_Xpar_4468_sm.webp

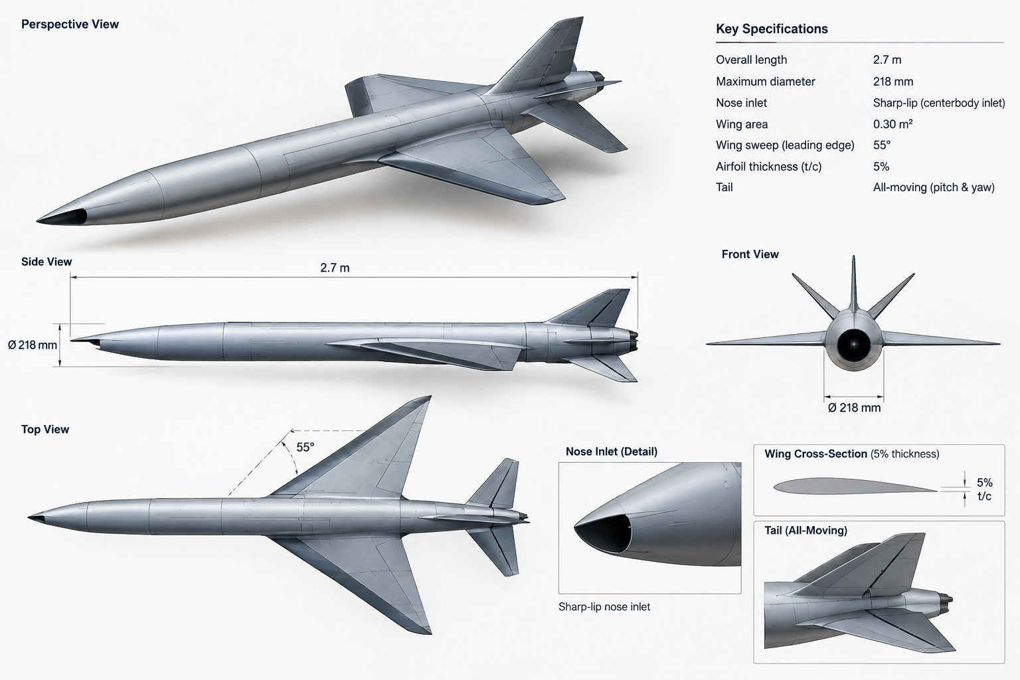
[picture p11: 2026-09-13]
ChatGPT Image Sep 13, 2026, 03_55_36 PM.png

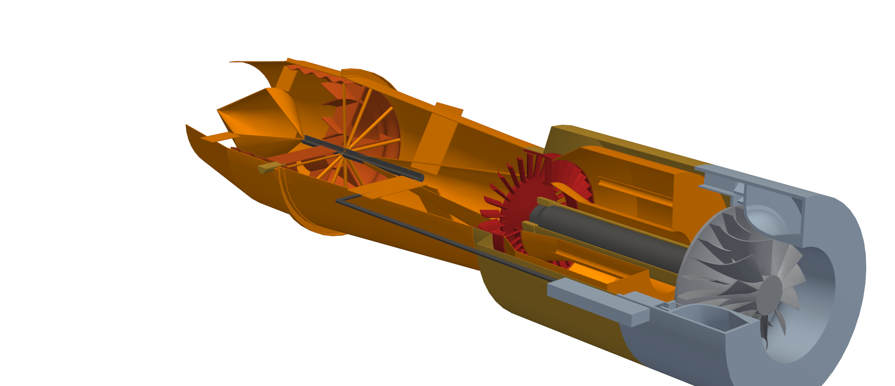
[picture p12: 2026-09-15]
plots/phase7_ab_cutaway.png

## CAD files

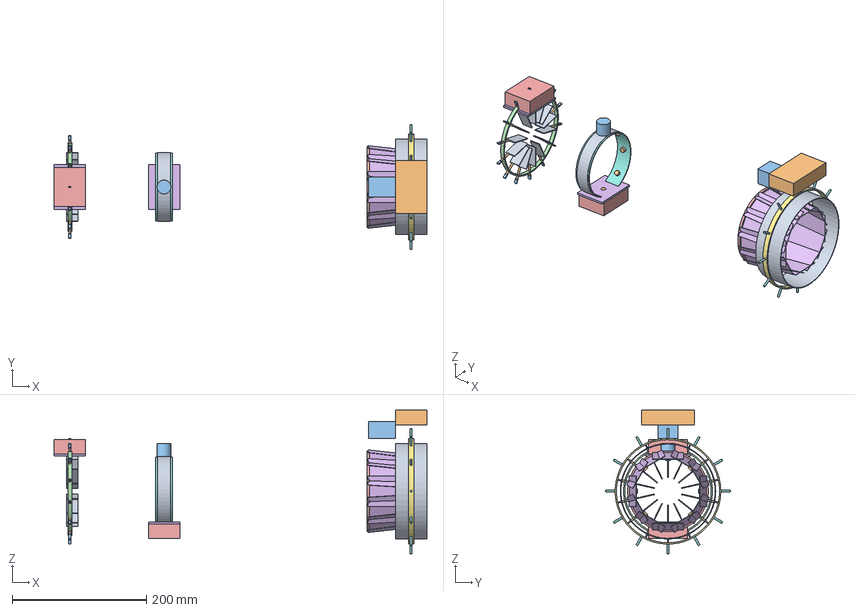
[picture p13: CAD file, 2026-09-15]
axial/cad/axial_vg_assembly.step
556.0 x 186.7 x 214.2 mm

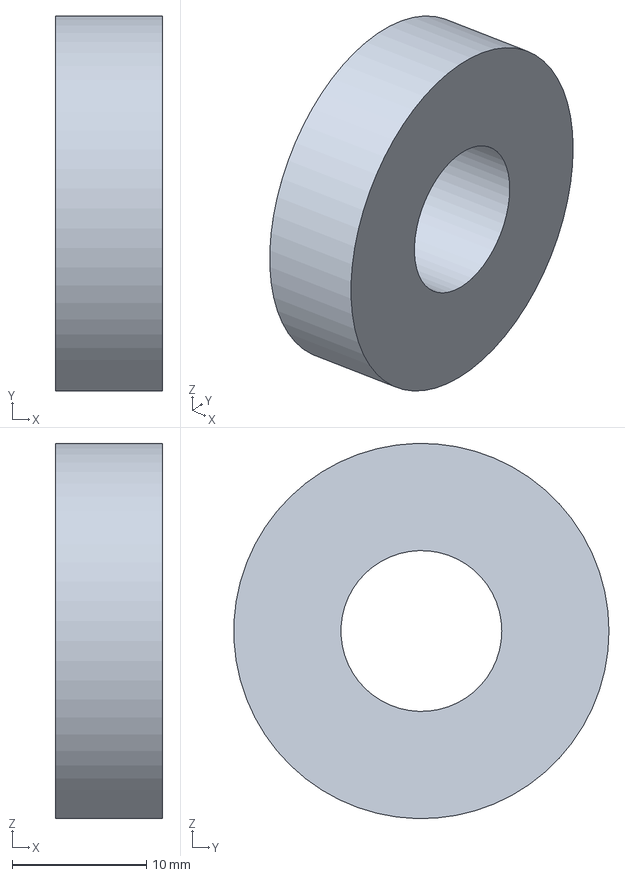
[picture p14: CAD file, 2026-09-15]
axial/cad/parts/bearing_rear.step
8.00 x 28.0 x 28.0 mm

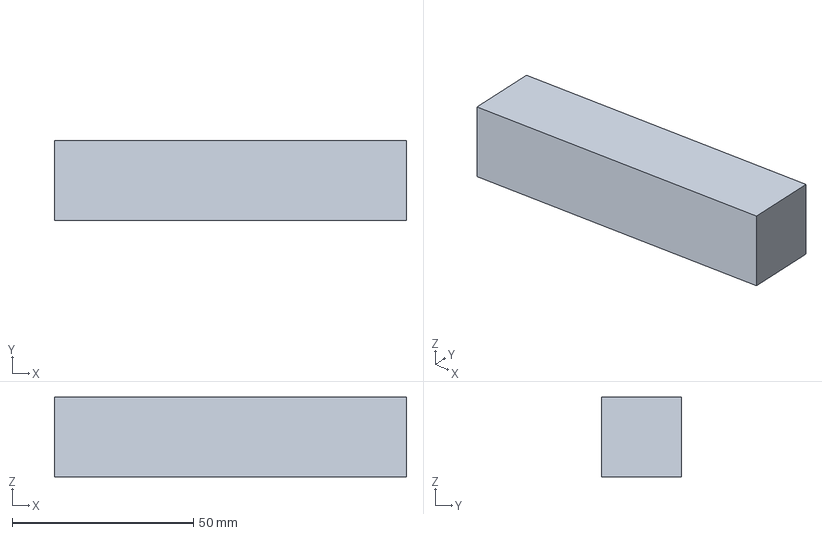
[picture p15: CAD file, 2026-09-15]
cad/afterburner/nozzle_actuator.step
97.0 x 22.0 x 22.0 mm

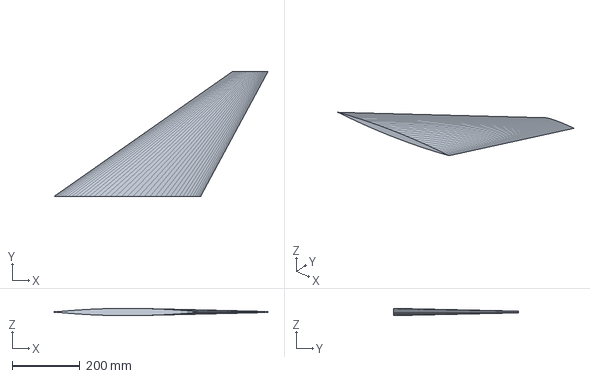
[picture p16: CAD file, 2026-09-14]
cad/airframe/wing_right.step
632.5 x 369.0 x 21.7 mm

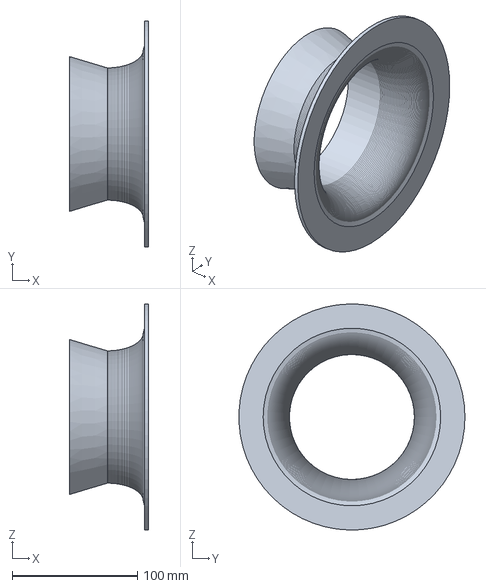
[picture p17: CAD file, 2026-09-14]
cad/engine/compressor_front_shroud.step
62.7 x 180.5 x 180.6 mm

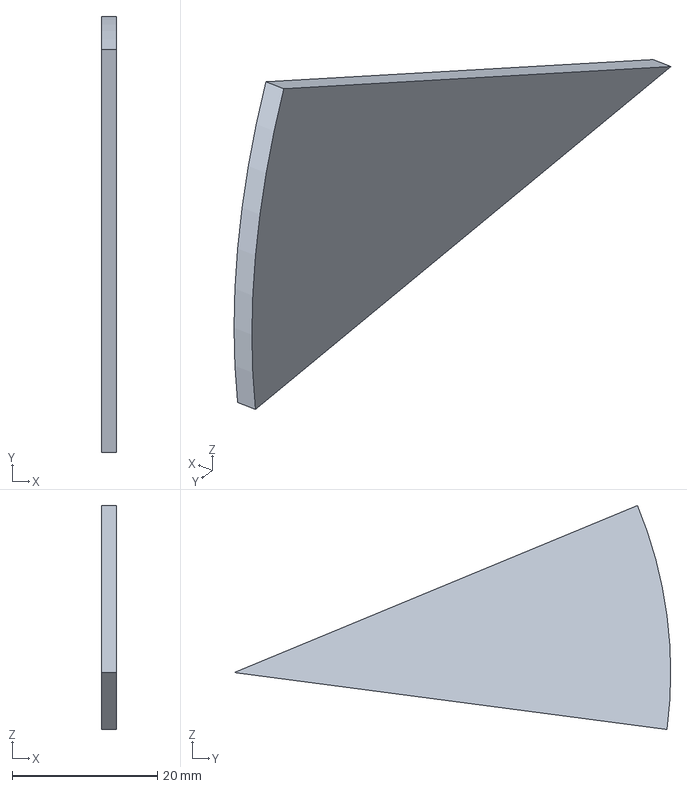
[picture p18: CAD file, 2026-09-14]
cad/fe/disc_sector.step
2.00 x 60.0 x 30.8 mm

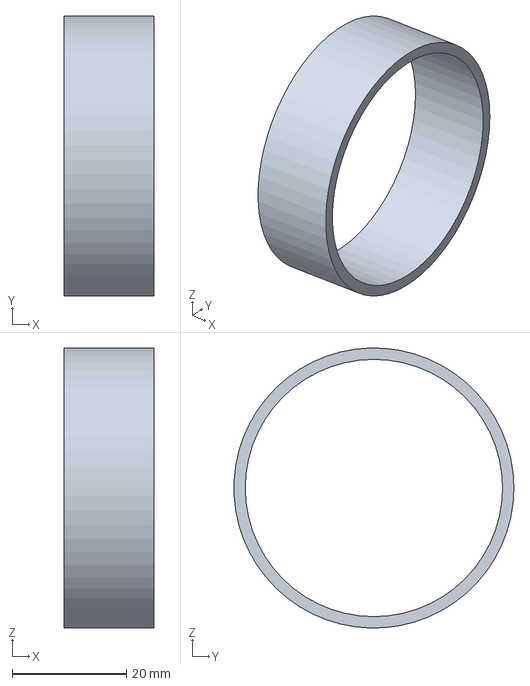
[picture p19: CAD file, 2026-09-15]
axial/cad/parts/stator_band_stage2.step
15.8 x 49.0 x 49.0 mm

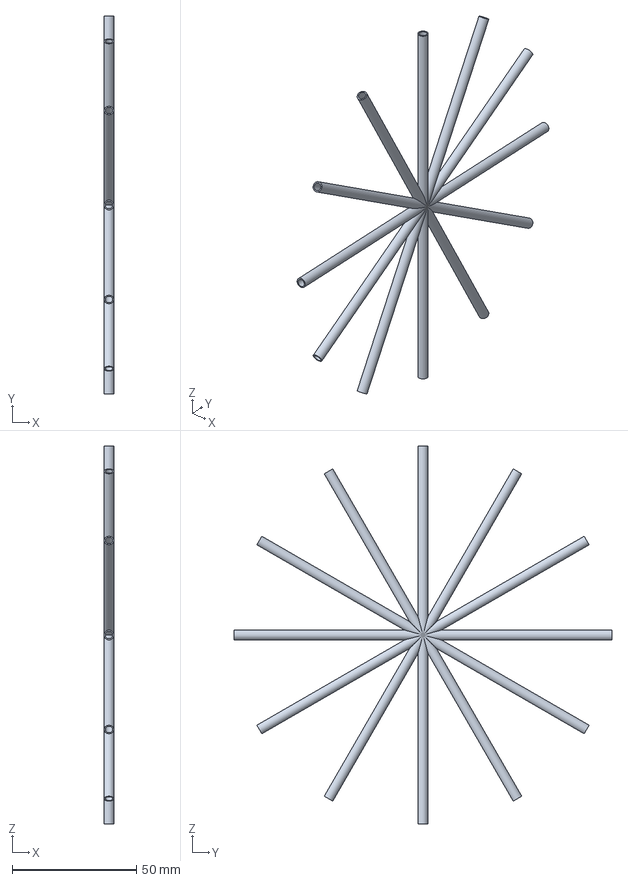
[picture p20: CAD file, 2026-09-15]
cad/afterburner/ab_spray_bars.step
4.00 x 152.2 x 152.2 mm

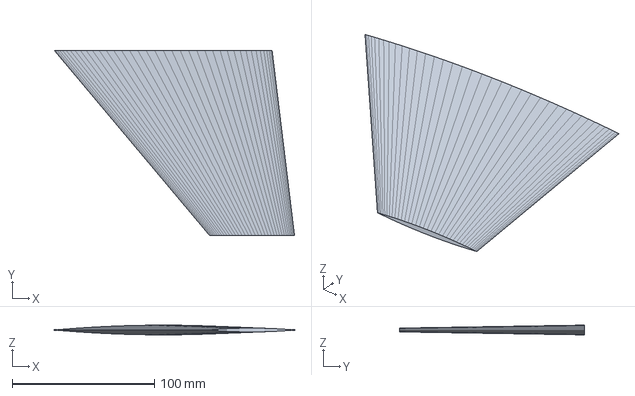
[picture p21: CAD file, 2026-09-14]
cad/airframe/htail_left.step
169.0 x 129.9 x 6.90 mm

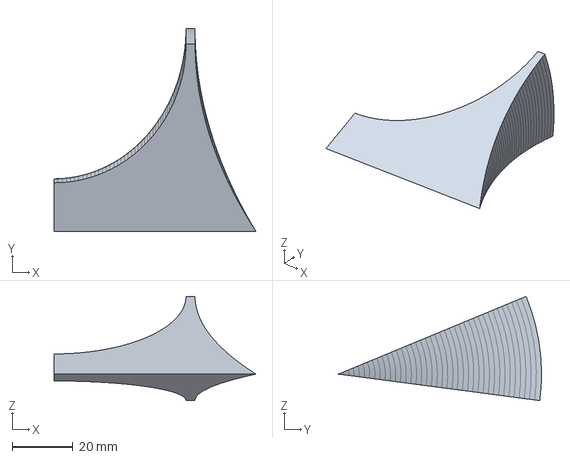
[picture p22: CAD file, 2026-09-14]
cad/fe/hub_sector.step
66.6 x 66.9 x 34.3 mm

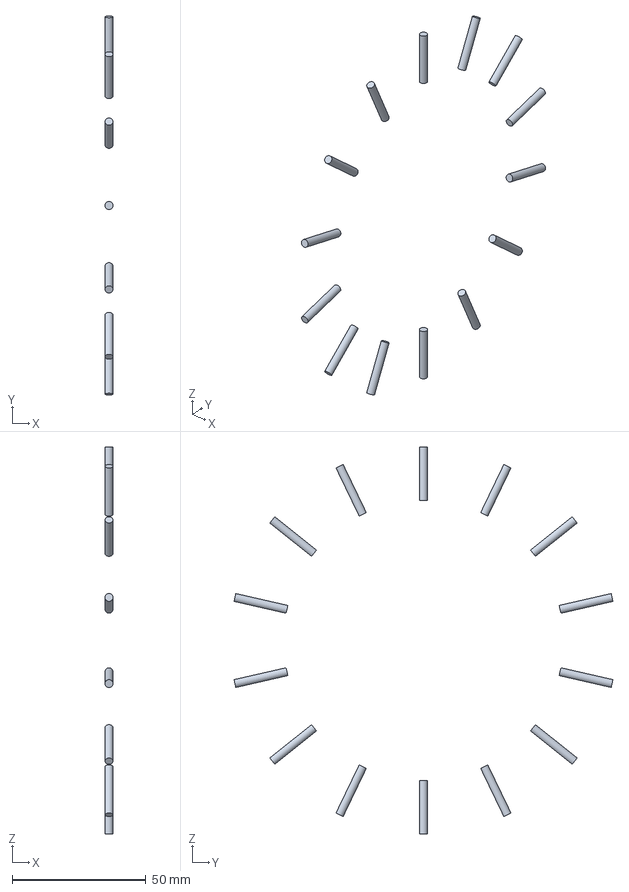
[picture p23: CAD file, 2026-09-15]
axial/cad/parts/vg_vigv_spindles.step
3.00 x 141.8 x 144.8 mm

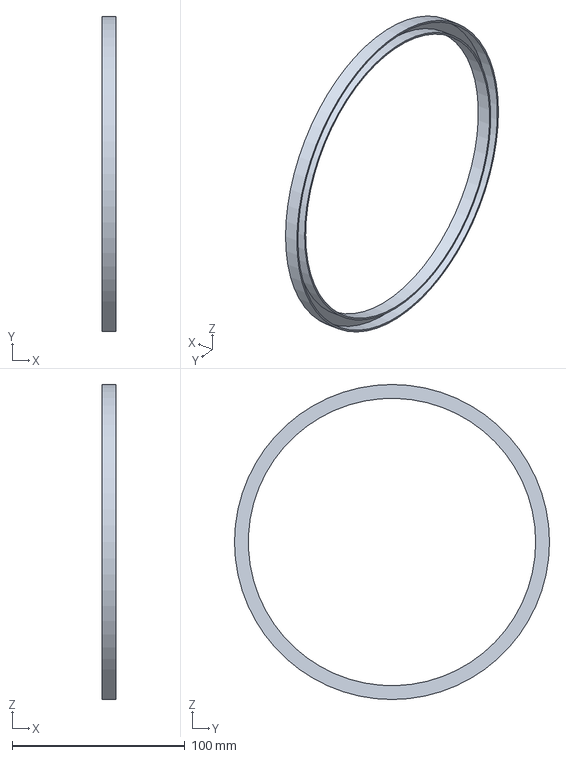
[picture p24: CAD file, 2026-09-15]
cad/afterburner/ab_fuel_manifold.step
8.00 x 182.2 x 182.2 mm

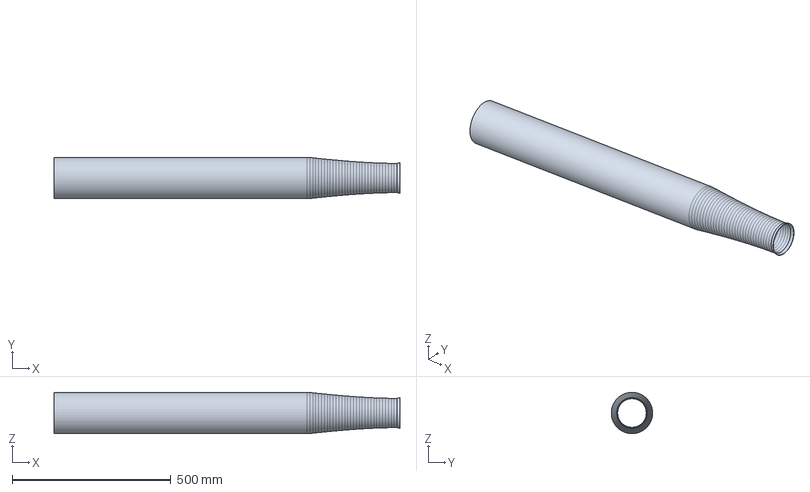
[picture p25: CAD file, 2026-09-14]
cad/airframe/jetpipe.step
1088.6 x 130.1 x 130.2 mm

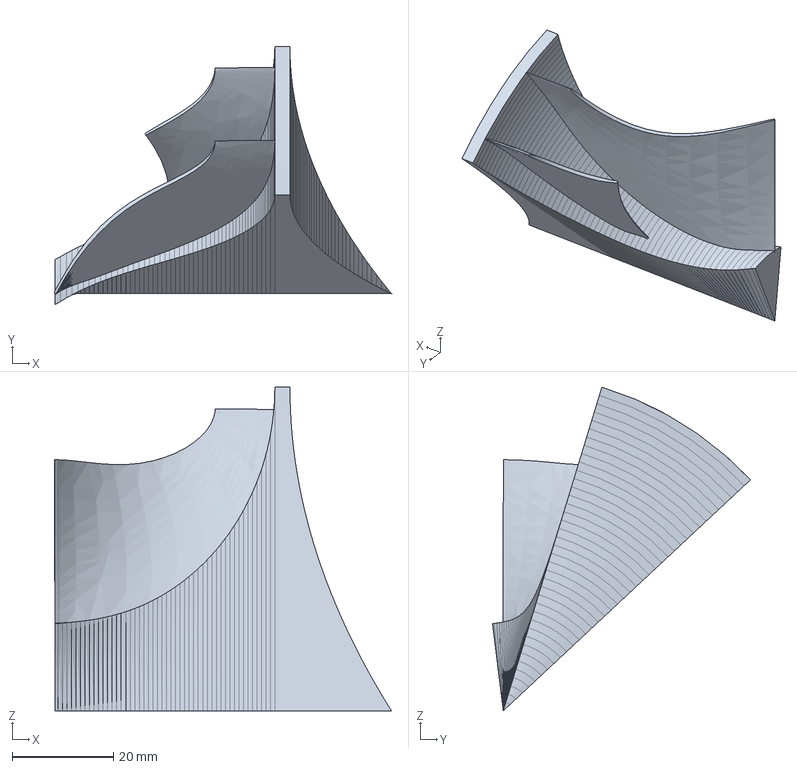
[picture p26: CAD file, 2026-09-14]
cad/engine/impeller_sector.step
66.6 x 51.0 x 64.0 mm

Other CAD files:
cad/fe/hub_sector_twisted.step
axial/cad/parts/housing_front.step
cad/afterburner/ab_tail_cone.step
cad/airframe/vtail.step
axial/cad/parts/bearing_front.step
axial/cad/parts/compressor_casing.step
axial/cad/parts/disc_stage1.step
axial/cad/parts/disc_stage2.step
axial/cad/parts/disc_stage3.step
axial/cad/parts/disc_stage4.step
axial/cad/parts/disc_stage5.step
axial/cad/parts/disc_stage6.step
axial/cad/parts/hot_casing.step
axial/cad/parts/housing_rear.step
axial/cad/parts/liner_dome.step
axial/cad/parts/liner_inner.step
axial/cad/parts/liner_outer.step
axial/cad/parts/ngv_hub_ring.step
axial/cad/parts/ngv_shroud_ring.step
axial/cad/parts/ngv_vanes.step
axial/cad/parts/nozzle_outer_cone.step
axial/cad/parts/rotor_blades_stage1.step
axial/cad/parts/rotor_blades_stage2.step
axial/cad/parts/rotor_blades_stage3.step
axial/cad/parts/rotor_blades_stage4.step
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

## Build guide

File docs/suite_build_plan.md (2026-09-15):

# jetsuite: build plan, milestones and development checklists

**Status (2026-09-15): nothing built yet.** This plan builds the architecture in `docs/suite_architecture.md`
(referred to below as "arch §n"). Engineering gaps and checks E1-E3 are in `docs/suite_coverage_review.md`.

**How to use this document:**
* Work one **step** at a time. A step is one unticked task box below, small enough for one commit.
* Every step follows the loop in section 4 and ends with the Definition of Done (section 4.3).
* Tick a box only with evidence: the command you ran and the file or output that shows it. Record it in the
  progress log (section 8).
* If a step shows the architecture is wrong, stop, change `docs/suite_architecture.md` first (arch §14), then continue.

---

## 1. Build strategy in one paragraph

Build **inside-out and behind a safety net**:
1. **M0:** golden tests that pin today's committed results, so nothing that follows can silently change a number.
2. **M1, M2:** the pure core (domain and application), tested with fake evaluators. This gives a *walking skeleton*:
   the whole flow from study to promotion report runs end to end in seconds, with no physics.
3. **M3, M4:** swap in the real store, executor and legacy-physics adapters one port at a time. After each swap, the
   same tests must still pass.
4. **M5 onward:** grow the CLI, Claude Code integration, levels and search.

The order is chosen for a reason. The rules are where mistakes are cheapest to find (milliseconds, no solvers). The
legacy physics is where mistakes are most expensive (minutes to hours, memory limits).

---

## 2. Prerequisites (before the first step)

- [ ] **The repository-split commit has landed.** The other agent has ~323 files staged (the axial quarantine). The
      suite must branch from a commit that contains it, and its SHA becomes the golden baseline.
- [ ] The three venvs work in the main checkout (`smoke_pycycle.py`, `smoke_turboflow.py`, `smoke_cad.py`).
- [ ] Open decisions with a proposed default (arch §13) are accepted or changed by the user. M0 needs only #1 (name
      and location); the rest can wait for their milestone.
- [ ] The user has decided whether engineering checks E1-E3 run in parallel. They are not needed until M8.

---

## 3. How to start: day one

PowerShell, from the main checkout (`boomsonic_v0`).

### 3.1 Record the baseline and create the worktree

```powershell
git log -1 --format="%H %cd"                        # the baseline commit, written into suite/BASELINE.md below
git worktree add ..\boomsonic_suite -b suite/m0-foundations
```

The venvs are gitignored, so the worktree has none. The legacy scripts find `.venv-np1` relative to their own repo
root, so the worktree needs them. Link the three venvs in as directory junctions (ADR-0008):

```powershell
foreach ($v in ".venv", ".venv-np1", ".venv-cad") {
    New-Item -ItemType Junction -Path "..\boomsonic_suite\$v" -Target (Resolve-Path $v)
}
```

**Caution:** the venvs are shared through the junctions. Never `uv pip install` from the worktree without following
checklist C (refreeze the requirements file, log it).

Check that the links work:

```powershell
cd ..\boomsonic_suite
.venv\Scripts\python scripts\phase0_tools\smoke_pycycle.py
.venv-np1\Scripts\python -c "import turboflow; print('np1 ok')"
.venv-cad\Scripts\python -c "import cadquery; print('cad ok')"     # judge by the output, not the exit code
```

### 3.2 Create the skeleton

Directories from arch §9:

```powershell
$d = "suite/src/jetsuite/domain", "suite/src/jetsuite/app", "suite/src/jetsuite/adapters/legacy",
     "suite/src/jetsuite/adapters/evaluators/centrifugal", "suite/src/jetsuite/adapters/store",
     "suite/src/jetsuite/adapters/executor", "suite/src/jetsuite/adapters/provenance",
     "suite/src/jetsuite/adapters/config", "suite/src/jetsuite/adapters/search", "suite/src/jetsuite/adapters/cli",
     "suite/src/jetsuite/workers", "suite/config", "suite/studies", "suite/gates", "suite/docs/adr",
     "suite/tests/unit", "suite/tests/architecture", "suite/tests/contract", "suite/tests/golden",
     "suite/tests/verification"
$d | ForEach-Object { New-Item -ItemType Directory -Force $_ | Out-Null }
```

Add an empty `__init__.py` to every package directory under `src/jetsuite/`.

Append to `.gitignore`:

```
suite/runs/
suite/.store/
```

`suite/pyproject.toml`. No install; pytest runs from `src` (ADR-0007):

```toml
[project]
name = "jetsuite"
version = "0.0.1"
requires-python = ">=3.12"

[tool.pytest.ini_options]
pythonpath = ["src"]
testpaths = ["tests"]
markers = [
    "contract: a real adapter against its port on a tiny case",
    "golden: reproduction of committed results",
    "verification: a tool against closed-form or published results",
    "slow: L3 and above",
]
```

`suite/jetsuite.py`, the CLI shim. It fails cleanly until M5 provides `main`:

```python
"""jetsuite CLI shim: puts suite/src on sys.path (no install into the frozen venvs, ADR-0007)."""
import pathlib, sys
sys.path.insert(0, str(pathlib.Path(__file__).resolve().parent / "src"))
from jetsuite.main import cli    # M5
cli()
```

### 3.3 The first three tests

**(a) The dependency rule** (`suite/tests/architecture/test_dependency_rule.py`), arch §3.2:

```python
"""Imports point inward only. domain: stdlib; app: stdlib + domain; protocol: stdlib."""
import ast, pathlib, sys
SRC = pathlib.Path(__file__).resolve().parents[2] / "src" / "jetsuite"
ALLOWED = {"domain": {"jetsuite.domain"}, "app": {"jetsuite.domain", "jetsuite.app"}, "protocol.py": set()}

def imported(path):
    pkg = path.relative_to(SRC.parent).with_suffix("").parts[:-1]     # e.g. ('jetsuite', 'domain')
    for node in ast.walk(ast.parse(path.read_text(encoding="utf-8"))):
        if isinstance(node, ast.Import):
            yield from (a.name for a in node.names)
        elif isinstance(node, ast.ImportFrom):
            if node.level == 0:
                yield node.module
            else:                                                    # resolve relative imports: '..app' must not escape
                base = pkg[:len(pkg) - (node.level - 1)]
                yield ".".join(base + ((node.module,) if node.module else ()))

def violations(ring):
    target = SRC / ring
    files = [target] if target.is_file() else sorted(target.rglob("*.py"))
    for f in files:
        for mod in imported(f):
            top = mod.split(".")[0]
            if top in sys.stdlib_module_names: continue
            if any(mod == a or mod.startswith(a + ".") for a in ALLOWED[ring]): continue
            yield f"{f.relative_to(SRC)} imports {mod}"

def test_inner_rings_import_inward_only():
    bad = [v for ring in ALLOWED if (SRC / ring).exists() for v in violations(ring)]
    assert not bad, "\n".join(bad)
```

Test the test: add `import numpy` to a domain file, confirm the test fails, then remove it.

**(b) Golden G1: the fielded dash cycle** (`suite/tests/golden/test_g1_dash_cycle.py`). This is the CLAUDE.md
reproduction target (W 1.32575 kg/s, TSFC 0.16416). The expected values are **read from the committed file**, never
typed:

```python
import csv, pathlib, sys, pytest
ROOT = pathlib.Path(__file__).resolve().parents[3]

@pytest.mark.golden
def test_fielded_dash_cycle_reproduces_phase3():
    rows = csv.DictReader(open(ROOT / "data" / "phase3_cycle_trade.csv", newline=""))
    ref = next(r for r in rows if r["level"].startswith("fielded") and r["nozzle"] == "CV"
               and float(r["T4"]) == 1150.0 and float(r["OPR"]) == 4.0)
    sys.path.insert(0, str(ROOT / "scripts" / "phase3_cycle"))     # tests are ring 4; adapters will own this later
    import dash_cycle as dc
    cyc, _ = dc.design(4.0, 1150.0, 0.70, 0.75)
    assert cyc["W_kgps"] == pytest.approx(float(ref["W"]), rel=1e-5)
    assert cyc["TSFC_kgpNh"] == pytest.approx(float(ref["TSFC"]), rel=1e-5)
```

If it fails, **stop**. That is a finding about the baseline, not a tolerance to loosen.

**(c) A domain smoke test** (`suite/tests/unit/test_smoke.py`): `import jetsuite.domain` works.

Run:

```powershell
.venv\Scripts\python -m pytest suite -m "not contract and not golden and not verification and not slow"   # fast gate
.venv\Scripts\python -m pytest suite -m golden
```

### 3.4 Close day one
- [ ] `suite/BASELINE.md` has the commit SHA and date, and lists the golden sources (the files the expected values
      are read from).
- [ ] ADR-0001 (clean architecture) written from the template in section 6.
- [ ] Commit: `Suite M0: skeleton, dependency-rule test, golden G1`.

---

## 4. The checklist for every development step

### 4.1 Definition of Ready (before starting a step)
- [ ] The step is **one** unticked task box in section 7.
- [ ] I know which ring the change lives in (arch §3.2), and that it doesn't pull an import outward.
- [ ] I know which test will prove it, and the test can be written before the code.
- [ ] No open decision (arch §13) blocks it.
- [ ] I am in the suite worktree on a `suite/...` branch, and the fast gate is green before I start.

### 4.2 The step loop
1. **Write or extend the test first.** For a domain rule, a table of cases. For an adapter, the port's contract test.
2. **Write the smallest change** that makes it pass.
3. **Run the fast gate** (unit + architecture, < 15 s).
4. **Touched an adapter or `scripts/`?** Run contract + golden (quick verify).
5. **Touched a tool, a tolerance or a band?** Run the relevant verification tests too.
6. **Check `git status data/`:** it must be clean (arch §6.1 rule 3).
7. **Update the docs.** An architecture change goes into the architecture doc + its change record; a decision gets an
   ADR; a new command goes into `suite/README.md`.
8. **Engineering numbers.** If any engineering number changed or is new, write a `design_log.md` **draft** for the
   user. Nothing goes into the log unreviewed.
9. **Commit:** `Suite Mk: <what changed>`.
10. **Tick the box** and add the evidence to the progress log (section 8).

### 4.3 Definition of Done (per step)
- [ ] The test was written before the code, and it passes.
- [ ] Fast gate green; dependency-rule test green.
- [ ] Contract and golden tests green, if an adapter or `scripts/` was touched.
- [ ] `git status data/` clean; no stray files outside `suite/`, `.claude/`, `data/suite/`.
- [ ] No new dependency; or checklist C completed.
- [ ] Every new number has a source (a `Metric` with a source, or a citation in config).
- [ ] No open risk presented as resolved; validity flags still attached where they apply.
- [ ] Docs, ADR and README updated as needed; a design-log draft exists if engineering numbers moved.
- [ ] Committed with the `Suite Mk:` prefix; box ticked with evidence.

### 4.4 Checklists for specific kinds of step

**A. Adding or changing a domain rule** (ring 1)
- [ ] A table-driven unit test with edge cases: zero margin, a band of zero, an `unknown` band, every verdict kind.
- [ ] Standard library only (the dependency-rule test proves it).
- [ ] Pure: no I/O, clock or randomness except through arguments.
- [ ] The rule produces an explanation string, and a test checks that it names the constraint, value, limit, band and
      case.
- [ ] If it changes gate behaviour: ADR-0006 updated.

**B. Adding an evaluator adapter** (ring 3)
- [ ] An Appendix C row exists (id, level, wrapped entry point, venv, resource class, per-case flag). Add the row
      first if it is missing.
- [ ] It declares `requires`, `provides`, `sources` and `validity`.
- [ ] Legacy output goes to the artefact directory; `git status data/` is clean after a real run.
- [ ] The legacy call runs in a fresh subprocess if it touches globals or env vars.
- [ ] Every output is a `Metric` with a unit and a source.
- [ ] Environment validity checks are implemented as flags.
- [ ] Contract test: the port's behaviour on a tiny real case, including a forced failure that comes back as a failed
      `Result`, not an exception.
- [ ] Golden test: it reproduces the committed result the legacy script produced.
- [ ] Wall time and peak memory measured and put into arch §8.

**C. Adding a third-party tool** (a mini Phase 0; brief rule 3)
- [ ] The candidate identified exactly: name, version, source. Watch for name collisions (PyPI `pycycle` and
      `pyturbo` are unrelated packages).
- [ ] Installed in the right venv with `uv pip`; the `requirements-*.txt` refrozen; nothing else in that venv changed
      (diff the freeze).
- [ ] A smoke test against a closed-form or published result, with its error recorded.
- [ ] Its defects and limits written as validity rules (Appendix B) and in `tools_survey.md`.
- [ ] Its error band added (Appendix A) with status `cited` or `measured`.
- [ ] A `design_log.md` draft: tool, inputs, outputs, why it was chosen over the alternatives.
- [ ] Used only through an adapter behind a port.

**D. Adding a validity rule**
- [ ] It has an id, the tool it applies to, a kind (metric / environment), an action and a source (design-log entry or
      tools_survey section).
- [ ] Linked to a risk id if one applies.
- [ ] A test triggers it and a test shows it silent on a valid case.
- [ ] `refuse` rules: a test shows the evaluator will not run.

**E. Changing an error band**
- [ ] The change comes from `EstimateBands` (measured pairs) or from a new cited source, never from convenience.
- [ ] A design-log draft with the old value, the new value, the evidence and the number of pairs.
- [ ] **The user accepts it before it takes effect** (arch §5.2).
- [ ] Re-run the gates of every study that has results at the affected level, and report what changed.

**F. Touching a legacy script under `scripts/`**
- [ ] The only allowed change is **parameterisation**: a new argument, env var or output-path hook whose default
      equals today's behaviour.
- [ ] The golden tests and the script's own verification pass unchanged.
- [ ] The script still runs standalone exactly as documented in `README.md`.
- [ ] NumPy-1 scripts stay standalone (file in, file out; no imports from the `.venv` side).
- [ ] A line in the step's commit message says which script changed and why.
- [ ] Mention it to the user: other agents work on `scripts/` too.

**G. Changing the store schema**
- [ ] A migration step (version table) and a test that migrates an old database.
- [ ] Cache keys unaffected, or bumped deliberately with an ADR.
- [ ] The in-memory and SQLite repositories pass the same contract tests.

**H. Adding a CLI command or a Claude Code skill**
- [ ] It maps to exactly one use case (arch §6.6).
- [ ] Output is at most about 40 lines of text, and full JSON with `--json`.
- [ ] A skill states what it must never do: tick gates, edit golden files, append to `design_log.md` without review.
- [ ] Documented in `suite/README.md`.

**I. Closing a milestone**
- [ ] Every task box ticked with evidence.
- [ ] Full test run: fast + contract + golden + verification (+ slow if the milestone touched L3 and above). The run
      time is recorded.
- [ ] `docs/suite_architecture.md` matches what was built (or its change record says where it differs).
- [ ] The progress log is updated; the milestone branch is merged or rebased as the user decides.
- [ ] A short summary for the user: what now works, what does not, what the next milestone needs from them.

---

## 5. Milestones

| id | goal | depends on | exit criterion | size |
|---|---|---|---|---|
| **M0** | foundations and safety net | prerequisites | golden G1, G2 and quick verification green in the worktree; timings measured | M |
| **M1** | domain core (ring 1) | M0 | every domain rule tested; worked examples from the freeze pass | M |
| **M2** | application core with fakes (walking skeleton) | M1 | study → evaluation → promotion report end to end with fakes, < 10 s | M |
| **M3** | infrastructure adapters | M2 | SQLite, executor, provenance and config pass the same contracts as the fakes | M |
| **M4** | legacy adapters L1-L2 + baseline study | M3 | `EvaluateDesign(baseline, L2)` reproduces G1 / G2 through the suite; `data/` untouched | L |
| **M5** | CLI + Claude Code integration | M4 | Claude takes a study to a promotion report with no manual script call | M |
| **M6** | L0, measured bands, real screening | M4 | bands measured on ≥ 30 designs and accepted by the user; `screen` + `promote` run on the real chain | L |
| **M7** | search and uncertainty | M6 | rediscovery test; UQ on the baseline with sourced inputs | L |
| **M8** | L3-L4 in the pipeline | M4 + E1-E3 results | hot / cold / ISA gates on the real deck; closure and rotor goldens reproduce | L |
| **M9** | L5 and high-fidelity additions | M8 + user gate | L5 refused without a gate record; each addition passed checklist C | L per addition |
| **M10** | architecture plugins, shared-module clean-up | M8 | the axial plugin works under `axial/`; old import paths still resolve | M |

```mermaid
flowchart LR
  P[prerequisites] --> M0 --> M1 --> M2 --> M3 --> M4
  M4 --> M5
  M4 --> M6 --> M7
  E[E1-E3 engineering checks, user go-ahead] --> M8
  M4 --> M8 --> M9
  M8 --> M10
```

Sizes are relative (S / M / L), not time estimates. M0's timings will make them concrete.

---

## 6. ADR template

`suite/docs/adr/NNNN-short-title.md`:

```markdown
# NNNN. Title
Date: YYYY-MM-DD. Status: proposed | accepted | superseded by NNNN
## Context        what forces the decision (link the architecture driver D1-D8)
## Decision       what we do
## Alternatives   what else was considered, and why not (with numbers where there are any)
## Consequences   what gets easier, what gets harder, what to watch
```

---

## 7. Milestone task lists

Each box is one step. The "evidence" column is what ticks it.

### M0: foundations and safety net

| ✓ | step | evidence |
|---|---|---|
| [ ] | 0.1 baseline recorded in `suite/BASELINE.md` (SHA, date, golden source files) | file |
| [ ] | 0.2 worktree + venv junctions; the three import checks of 3.1 pass | command output |
| [ ] | 0.3 skeleton, `pyproject.toml`, shim, `.gitignore` entries, `suite/README.md` | tree listing |
| [ ] | 0.4 dependency-rule test green; shown to fail on a deliberate bad import | two test runs |
| [ ] | 0.5 golden G1 (fielded dash cycle vs `data/phase3_cycle_trade.csv`) | test run |
| [ ] | 0.6 golden G2: `cc_trade.py reeval` of the baseline with `P3_DATA` pointed at a temp dir reproduces `data/phase3r/cct_ce75000_opr4_t1150_b15_cap.json` (fielded D, mass, margins, TOGW, worst corner). **Tolerance measured**: run twice, take the spread, set the tolerance above it, and write it into the test | test run + tolerance note |
| [ ] | 0.7 "data/ untouched" architecture test (fails if a test run leaves `git status data/` dirty) | test run |
| [ ] | 0.8 verification wrappers, quick set: `verify_axisym_fe`, `rotordynamics_verify`, `impeller_stress` (regression vs the gate), `verify_turboflow_slip` (np1), `verify_aero_tools`, `smoke_cantera`. Tolerances from the design-log numbers. Scripts that regenerate committed files are checked by "regenerated == committed", which doubles as a reproducibility check | test run |
| [ ] | 0.9 verification wrappers, full set: the rest of the CLAUDE.md commands list (`smoke_*`, `validate_mass_model` 3R, `cc_benchmark`, `hecc_surge_check`, `td_check`, `smoke_cad`, `fe3d_impeller A,B,BT`) | test run + run time |
| [ ] | 0.10 timing: wall time and peak memory of every "existing" Appendix C entry point; arch §8 updated from estimates | table in arch §8 |
| [ ] | 0.11 ADRs 0001-0008 written | files |
| [ ] | 0.12 milestone close (checklist I) | summary to user |

### M1: domain core (ring 1, stdlib only)

| ✓ | step | evidence |
|---|---|---|
| [ ] | 1.1 `Metric`, `Variable`, `AtmosphereCase` with invariants (a metric without a source cannot be built) | unit tests |
| [ ] | 1.2 `Requirements`, `TechLevel`, `Installation`, `Study`, `Design`, `Level` | unit tests |
| [ ] | 1.3 `design_id`: canonical JSON; stable across key order, float formatting and process runs | unit tests |
| [ ] | 1.4 `ConstraintSpec`, `normalised_margin`, `verdict` (all six verdict kinds; `unknown` band never gives `pass`) | table test |
| [ ] | 1.5 `worst_case` over atmosphere cases, naming the binding case | unit tests |
| [ ] | 1.6 `promotion` policy (all pass; uncertain allowed only within budget) | unit tests |
| [ ] | 1.7 `pareto` with an ε-band | hand-worked examples |
| [ ] | 1.8 `estimate_band` from pairs (quantile) | unit tests |
| [ ] | 1.9 `ValidityRule`, `ValidityFlag`, `apply_validity` (metric predicates; flag / refuse / monitor_only) | unit tests |
| [ ] | 1.10 verdict explanations (constraint, value, limit, band, case, "because ...") | unit tests |
| [ ] | 1.11 worked examples from the freeze as tests: TOGW margin 4.91 kg against a ±0.36 kg mass band passes; surge is `monitor_only`; the exducer root is `sized_to_limit` | unit tests |
| [ ] | 1.12 milestone close | summary |

### M2: application core with fakes (walking skeleton)

| ✓ | step | evidence |
|---|---|---|
| [ ] | 2.1 `ports.py`: every port of arch §5.1 as a `typing.Protocol` | dependency test |
| [ ] | 2.2 fakes in `tests/`: in-memory repository, in-process executor, fake evaluators with analytic "physics" | unit tests |
| [ ] | 2.3 DAG planning with `graphlib` (topological order, cycle detection, the cross-level L4 → L3 edge) | unit tests |
| [ ] | 2.4 cache key (arch §5.4) with the provenance probe faked | unit tests |
| [ ] | 2.5 `EvaluateDesign`: hit / miss, leases (two threads, one computation), validity, verdicts, atmosphere cases | unit tests |
| [ ] | 2.6 failures as results: a fake evaluator that raises returns a cached failed `Result` | unit tests |
| [ ] | 2.7 `Screen` (fake sampler) and `Promote` | unit tests |
| [ ] | 2.8 `CheckGate`: L5 refused without a gate record, allowed with one | unit tests |
| [ ] | 2.9 `EstimateBands` produces a proposal only (no effect until accepted) | unit tests |
| [ ] | 2.10 end-to-end walking skeleton: study object → screen → promote → report data, fakes only, < 10 s | test run |
| [ ] | 2.11 milestone close | summary |

### M3: infrastructure adapters

| ✓ | step | evidence |
|---|---|---|
| [ ] | 3.1 port contract tests written once, run against the fakes and the real adapters | test run |
| [ ] | 3.2 config loader: YAML → pydantic DTOs → domain; `studies/baseline_ce75000.yaml` with every value sourced and equal to today's hard-coded values (`dash_cycle.py:18-20`; `arch_trade.py:146-151`; `S_wing=0.30` also in `cc_closure.py:87`, `cc_mission.py:152`, `make_params.py:119`) | test + file |
| [ ] | 3.3 SQLite repository (WAL, leases, schema version) passes the repository contract | contract tests |
| [ ] | 3.4 artefact store under `suite/runs/` | contract tests |
| [ ] | 3.5 provenance: git SHA and dirty flag; AST import-closure content hashes; tool versions from `requirements-*.txt` | tests: editing a file in the closure changes the key; an unrelated file does not |
| [ ] | 3.6 `protocol.py` (stdlib only), imported and round-tripped under `.venv`, `.venv-np1` and `.venv-cad` | three command outputs |
| [ ] | 3.7 subprocess executor: resource classes (a third `map` job waits), timeouts, memory watchdog | contract tests |
| [ ] | 3.8 the walking skeleton re-run with the real store and executor (fake evaluators still) | test run |
| [ ] | 3.9 milestone close | summary |

### M4: legacy adapters L1-L2 and the baseline study

| ✓ | step | evidence |
|---|---|---|
| [ ] | 4.1 `adapters/legacy`: the only `sys.path` owner; subprocess runner; output redirection (absolute `P3_DATA`) | contract test |
| [ ] | 4.2 parameterise the design-point constants (`dash_cycle.py` M / H / Fn / η_b / duct length) with defaults equal to today (checklist F) | golden G1 unchanged |
| [ ] | 4.3 parameterise the airframe constants in `arch_trade.airframe` (S_wing, sortie-fuel scaling, accessories, growth, dash fuel fraction) the same way | golden G2 unchanged |
| [ ] | 4.4 `cc.L1.cycle`, `cc.L1.impeller_stress`, `cc.L1.combustor`, `cc.L1.mass`, `cc.L1.airframe` (checklist B each) | contract + golden per evaluator |
| [ ] | 4.5 `cc.L2.meanline` (coarse wrapper of `design_case` + `evaluate_all`) | reproduces G2 through the suite |
| [ ] | 4.6 `cc.L2.td_check` | reproduces `data/phase4r_td_check.json` |
| [ ] | 4.7 environment validity checks: V-TF-SLIP, V-TF-TURB, V-TF-GAS, V-TF-DIFF, V-TF-THROAT | trigger tests |
| [ ] | 4.8 `EvaluateDesign(baseline, L2)` end to end; `data/` untouched; a second run is 100 % cache hits | test run |
| [ ] | 4.9 milestone close | summary |

### M5: CLI and Claude Code integration

| ✓ | step | evidence |
|---|---|---|
| [ ] | 5.1 `main.py` composition root; `jetsuite.py` shim works | command output |
| [ ] | 5.2 click commands of arch §6.6 with text and `--json` presenters (checklist H each) | command outputs |
| [ ] | 5.3 markdown report and design-log draft presenters; the draft format matches existing `Dx.y` entries | sample outputs |
| [ ] | 5.4 skills: `new-study`, `promote`, `verify-tools`, `log-decision`, `add-tool`, `explain-result` | files + a trial run each |
| [ ] | 5.5 agents: `verifier`, `reviewer` (read-only tools) | files + a trial run each |
| [ ] | 5.6 `.claude/settings.json`: deny rules for `suite/gates/` and `suite/tests/golden/`; hooks (PreToolUse Bash guard, PostToolUse fast gate). **Syntax checked against the Claude Code docs** | files + a demonstration that a blocked write is blocked |
| [ ] | 5.7 dry run: Claude takes `baseline_ce75000.yaml` to a promotion report with no manual script call | transcript excerpt |
| [ ] | 5.8 milestone close | summary |

### M6: L0, measured bands, real screening

| ✓ | step | evidence |
|---|---|---|
| [ ] | 6.1 `cc.L0.cycle_closed_form` (ideal Brayton with the study's efficiencies), `cc.L0.envelope_fit`, `cc.L0.tip_stress` | contract tests; the closed form checked against pyCycle at the design point |
| [ ] | 6.2 `cc.L1.presize` extracted from `centrifugal_design.py` (its CoolProp dependence resolved) | agrees with TurboFlow's pre-sizing at the baseline |
| [ ] | 6.3 `scipy.stats.qmc` sampler adapter (seeded) | contract test |
| [ ] | 6.4 common sample of ≥ 30 designs evaluated at L0, L1 and L2 | results in the store |
| [ ] | 6.5 `bands propose` from the pairs → design-log draft → **user accepts** → `error_bands.yaml` updated (checklist E) | draft + user decision |
| [ ] | 6.6 decide open decision 4 (is L0 worth keeping?) from the timings | ADR |
| [ ] | 6.7 `screen` + `promote` on the real chain for the baseline study; report exported to `data/suite/` | report file |
| [ ] | 6.8 milestone close | summary |

### M7: search and uncertainty

| ✓ | step | evidence |
|---|---|---|
| [ ] | 7.1 surrogate and optimiser libraries chosen through checklist C (candidates: OpenMDAO surrogates and DOE, SMT, pymoo) | tools_survey + design-log draft |
| [ ] | 7.2 multi-fidelity surrogate (L1 trend + L2 correction), hold-out error reported | test run |
| [ ] | 7.3 `optimize` with every pick confirmed by the real L2 evaluator | test run |
| [ ] | 7.4 **rediscovery test:** with the baseline requirements and an open OPR × rpm × backsweep space, OPR 4 / 75 000 rpm / −15° is on or near the front, or the report explains why not with numbers | report |
| [ ] | 7.5 UQ input distributions, each with a source | `config/uq_*.yaml` |
| [ ] | 7.6 `uq` on the baseline: P(dash margin ≥ 25 %), input ranking, surrogate spot-checked with real runs | report |
| [ ] | 7.7 milestone close | summary |

### M8: L3-L4 in the pipeline

Needs the results of E1-E3 (coverage review) as golden values.

| ✓ | step | evidence |
|---|---|---|
| [ ] | 8.1 Python map driver replacing (or wrapping) the `.sh` runners; resource class `map` limits parallel maps to 2 | contract test; a map reproduces `data/phase3r/maps/...` |
| [ ] | 8.2 parameterise the output paths of `cc_mission.py`, `cc_closure.py`, `cc_rotor*.py`, `cc_transient.py` (checklist F) | goldens unchanged |
| [ ] | 8.3 `cc.L3.deck` with atmosphere cases (pyCycle temperature offset) | reproduces the ISA deck; E1 hot / cold values reproduce |
| [ ] | 8.4 `cc.L3.installed` (jetpipe loss, power extraction) | reproduces E1 |
| [ ] | 8.5 `cc.L4.rotor`, then `cc.L3.transient` with the I_p edge | reproduce `phase4r_rotor_final.json` (bending critical 105.6 krpm) and `phase4r_accel_*.csv` |
| [ ] | 8.6 `cc.L3.closure` | reproduces `data/phase4r_closure.json` (TOGW 20.09 kg) |
| [ ] | 8.7 `cc.L4.campbell` for all rows; `cc.L4.bearings`; `cc.L4.unbalance` | reproduce E2 / E3; unbalance verified against a closed form |
| [ ] | 8.8 `cc.L3.windmill_relight`, `cc.L3.decel` (new physics: checklist B, plus a verification case each) | tests |
| [ ] | 8.9 gate reports name the binding atmosphere case | report |
| [ ] | 8.10 milestone close (including the slow suite) | summary |

### M9: L5 and high-fidelity additions

| ✓ | step | evidence |
|---|---|---|
| [ ] | 9.1 `CheckGate` wired to `suite/gates/`; L5 refused without the user's record | test |
| [ ] | 9.2 `cc.L5.cad`, `cc.L5.fe3d` adapters | reproduce the Phase 6 results (`data/phase6/`) |
| [ ] | 9.3 each high-fidelity addition, one at a time on the user's choice, through checklist C: RANS on NASA HECC (then CC3 if sourced), Cantera reactor network against the reference engines, CalculiX against `fe3d_impeller.py` | per-addition verification report |
| [ ] | 9.4 milestone close | summary |

### M10: architecture plugins and shared-module clean-up

| ✓ | step | evidence |
|---|---|---|
| [ ] | 10.1 `ArchitecturePlugin` interface; the centrifugal evaluators moved behind it | all goldens unchanged |
| [ ] | 10.2 neutral common module for the generic map / off-design helpers (`axial_map`, `axial_offdesign.Choked`, `ac_offdesign.PureCC`); **thin re-exports at the old paths** | import-closure check; `README.md` commands still run |
| [ ] | 10.3 axial plugin under `axial/`, with V-AX-STACK on every result | test |
| [ ] | 10.4 milestone close | summary |

---

## 8. Progress log

| date | milestone.step | commit | evidence | note |
|---|---|---|---|---|
| | | | | |

---

## 9. Change record

| date | change |
|---|---|
| 2026-09-15 | first version |

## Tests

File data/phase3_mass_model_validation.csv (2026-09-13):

model | T4_for_thrust | D_pred | D_pub | D_comp | D_comb | D_turb | L_pred | L_pub | m_pred | m_pub | m_err_pct | note | eta_c_tool | eta_t_tool
JetCat P400-PRO-LN | 1384.3143153303472 | 145.44469996052896 | 148.4 | 130.71317230109818 | 145.44469996052896 | 98.15574642138962 | 319.4692021690475 | 390.0 | 3.4523659664879554 | 4.01 | -13.90608562374176 | incl. integrated ECU/pump | 0.7975342838942496 | 0.9191838310524628
AMT Nike | 1358.6755983707212 | 203.19302878702203 | 201.0 | 203.19302878702203 | 174.21970133866674 | 153.68070161215482 | 430.0218402369224 | 524.0 | 6.978119596421262 | 9.15 | -23.736397853319545 | engine only | 0.8337766056333339 | 0.9232921519265689

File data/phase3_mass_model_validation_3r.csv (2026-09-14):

model | T4_for_thrust | D_pred | D_pub | D_comp | D_comb | D_turb | L_pred | L_pub | m_pred | m_pub | m_err_pct | note | eta_c_tool | eta_t_tool
JetCat P400-PRO-LN | 1384.3143153303472 | 145.44469996052896 | 148.4 | 136.94077655121288 | 145.44469996052896 | 98.15574642138962 | 322.12170027557784 | 390.0 | 3.5201203396589147 | 4.01 | -12.216450382570699 | incl. integrated ECU/pump | 0.7999759557899608 | 0.9191838310524628
AMT Nike | 1358.6755983707212 | 212.40839045302286 | 201.0 | 212.40839045302286 | 174.21970133866674 | 153.68070161215482 | 433.94690168725606 | 524.0 | 7.228372645742528 | 9.15 | -21.00139184980844 | engine only | 0.8381411225000509 | 0.9232921519265689

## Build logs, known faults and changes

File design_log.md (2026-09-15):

# Design log — 500 N turbojet + <=25 kg airframe

Running record of every non-trivial decision: tool used, inputs, outputs, and why the
chosen option beat the alternatives. Newest entries at the bottom. IDs: `Dx.y` = decision,
`Ax.y` = assumption, `Fx.y` = finding, where x = phase.

---

## Phase 0 — Setup and tool survey (2026-09-13)

### A0.1 Reference condition for the 500 N thrust target (working assumption, not yet confirmed)
- **Assumed:** 500 N is **uninstalled net thrust at sea-level static (SLS), ISA (288.15 K,
  101.325 kPa), maximum continuous rating**, Jet-A / kerosene fuel.
- **Why this default:** it is the rating convention on every commercial micro-turbojet data
  sheet, so it is the only definition against which a statistical engine-mass database
  (needed for the 25 kg closure) can be built. Phase 1 will state the flight-condition
  thrust requirement separately from this rating.
- **Status:** flagged for the user; not load-bearing until Phase 1.

### D0.1 Python 3.12, not the machine default 3.14
- **Evidence:** Cantera 3.2.0 wheel metadata `requires_python <3.15,>=3.10`; turboflow
  `<4.0,>=3.11`; OpenMDAO/CoolProp untested on 3.14. 3.12.10 already present on the machine.
- **Result:** every candidate installed on 3.12.

### D0.2 Two virtual environments (`.venv` NumPy 2.5, `.venv-np1` NumPy 1.26)
- **Tool:** `uv pip install --dry-run`; import and functional tests.
- **Evidence:** `openmdao 3.45.1` needs `numpy>=2`; `turbodesigner 2.0.0` needs `numpy>=2.4.3`;
  `turboflow 0.1.18` needs `numpy<2`; `ADRpy 0.2.6` fails under NumPy 2 in `twrequired_to`
  (line 1505) and `liftslope_prad` (line 726). A one-line ADRpy patch was tried and exposed
  the second failure; the same ADRpy smoke test passes unmodified under NumPy 1.26.4.
- **Alternatives rejected:** patch ADRpy piecemeal (unbounded); downgrade the whole stack
  to NumPy 1 (breaks OpenMDAO). Tools in the two envs exchange only tabulated data.

### D0.3 pyCycle installed from GitHub, not PyPI
- **Finding F0.1:** PyPI `pycycle 0.0.8` is an unrelated circular-import detector
  (contents: `cli.py`, `utils.py`). Removed.
- **Installed:** `om-pycycle 4.4.1.dev0` @ `ee7e161` (2026-05-20, includes NumPy-2 thermo fix).
- **Verification (`scripts/phase0_tools/smoke_pycycle.py`):** single-spool turbojet, SLS,
  Fn target 11800 lbf, T4 2370 R, PR 13.5: Newton converged in 4 iterations; Fn 11800.0 lbf,
  W 147.33 lbm/s, TSFC 0.7985 lbm/hr/lbf; two off-design points at Fn 11000 lbf converged
  (Nmech 7944 rpm). Off-design capability confirmed, which is the reason to use pyCycle
  over a hand-written ideal-cycle script.

### D0.4 Cantera adopted as thermo cross-check and combustor-limit tool (not as the cycle solver)
- **Finding F0.2:** pyCycle already carries a CEA Gibbs-minimisation thermo (JP-7 default;
  Jet-A tabular). So Cantera's role is independent verification and combustor chemistry,
  not a replacement for pyCycle's gas model.
- **Verification (`smoke_cantera.py`):** n-dodecane surrogate, phi 0.30, T3 470 K, P3 4 bar:
  T_ad 1230.9 K, gamma 1.3065, cp 1231.7 J/kg-K. ISA air gamma 1.4015. Plausible for a
  micro-turbojet combustor (T4 in the 1100-1250 K range on published KJ66/JetCat data).

### D0.5 turbo-design (NASA) installed from GitHub main, pinned, adopted as Phase 4 primary
- **Finding F0.3:** PyPI `turbo-design 1.4.2` (2026-03) has stray `from turtle import down/up`
  lines (`turbine_spool.py:6`, `compressor_spool.py:3`) that require tkinter, absent on this
  Python build. GitHub main `1.4.3 @ 23c2b0b` has the lines removed and adds a dedicated
  `turbodesign.centrifugal` package, `operating_map`, and `shaft_match`.
- **Verification (`smoke_turbodesign.py`, upstream HECC fixture, sourced geometry, no tuning):**

  | quantity | model | NASA measured | error |
  |---|---|---|---|
  | work factor psi | 0.8127 | 0.8100 | +0.3 % |
  | stage PR_tt | 4.7805 | 4.6847 | +2.0 % |
  | stage eta_poly | 0.8540 | 0.8553 | -0.2 % |
  | choke mass flow | ~5.60 kg/s | 5.24 kg/s | +7 % |

  Plot: `plots/phase0_turbodesign_hecc_validation.png`. These error bands are carried
  forward as the uncertainty on any Phase 4 compressor number from this tool.
- **Why over TurboFlow as primary:** NASA-maintained, validated against a NASA test case
  with published geometry, handles both the centrifugal compressor and the axial turbine
  and shaft matching in one framework, Cantera gas model. TurboFlow is kept as the
  independent cross-check (different loss correlations: Oh / Zhang) and for its
  axial-turbine design optimiser.

### D0.6 TurboFlow adopted as Phase 4 secondary (cross-check, turbine design optimisation, maps)
- **Verification (`smoke_turboflow.py`, upstream example):** centrifugal compressor
  0.45 kg/s, 52 krpm, 143 mm impeller, Oh losses: converged 3.4 s, eta_tt 83.8 %, PR_tt 2.664.
  Axial-turbine design optimisation example: converged 99 s, eta_ts 90.8 %, PR_ts 2.298,
  geometry returned. Example machine is within a factor of ~2 of the expected 500 N scale.

### D0.7 Tools rejected or held
- **pyAircraftEngineFramework: rejected.** GitHub only (0 stars, one author, non-commercial
  Prosperity licence). On-design only: single `calculate(h, Ma)` method, fixed
  efficiencies, no maps, no deck export, no airframe coupling. Adds nothing over pyCycle.
- **TurboMAP: does not exist** as a Python turbomachinery package (PyPI and GitHub searched).
- **pyturbo-aero (NASA PyTurbo): held for Phase 6.** Geometry generator (`Centrif`,
  `Airfoil3D`), no performance model. PyPI `pyturbo` is an unrelated 2018 TensorFlow bundle.
- **turbodesigner (OpenOrion): held.** Axial compressor only; efficiency is an *input*.
  Runs at micro scale (0.9 kg/s, PR 3, 70 krpm: mean radius 58.7 mm, inlet Mach 0.45).
  Only relevant if an axial-compressor architecture survives the Phase 3 trade.

### D0.8 Gap-filling methods committed to (details in `tools_survey.md` section 3)
- Centrifugal compressor map for pyCycle off-design: generated in Phase 4 from
  turbo-design / TurboFlow speed lines, converted to pyCycle `MapData`. Placeholder scaled
  `AXI5` map in Phase 3 first pass, flagged as such.
- Engine mass: bottom-up geometry-based estimate plus a cited statistical micro-turbojet
  database; both reported.
- Airframe mass fractions: cited small-UAV weight-fraction data (Raymer, Gundlach).
- Engine deck to mission coupling: own script around pyCycle off-design output.

### F0.4 Early feasibility signal (placeholder inputs; to be redone properly in Phase 2)
ADRpy smoke run with generic small-jet aerodynamics gave required T/W of 0.3-0.6 across
W/S 150-800 Pa, versus T/W = 2.04 for 500 N on 25 kg. The mission definition in Phase 1
must justify roughly 3-6x more installed thrust than a conventional small jet UAV needs,
or the thrust rating vs sizing point must be reconciled. Carried into Phase 1 as the one
possible clarifying question.

---

## Phase 1 — Requirements and mission definition (2026-09-13)

User input resolving F0.4: RC-scale student project; the aircraft must reach and hold
Mach 1 for 7 s (that is why the thrust is high), take off from the ground from standstill,
land, and repeat the sortie once the same day. Airframe drag not yet computed by the user.
Full write-up: `docs/phase1_requirements.md`.

### F1.1 A 500 N *SLS-rated* engine gives only ~310-325 N at Mach 1 below 5 km
- **Tool:** pyCycle, `scripts/phase1_requirements/prelim_thrust_lapse.py` (placeholder
  cycle OPR 4 / T4 1150 K / eta_c 0.78 / eta_t 0.85, scaled NPSS maps; continuation sweep,
  residual-norm convergence check; both RPM-limited and T4-limited max throttle, lower taken).
- **Numbers:** M1 thrust 309 N (0 km), 325 N (1-5 km), 272 N (8 km), 226 N (10 km). RPM
  limit binds everywhere below 8 km; holding T4max at M1 / 0 km would need 104.7 % N.
- **Mechanism:** inlet total temperature 1.2x ambient at M1 -> corrected speed -9.5 % at
  fixed mechanical speed.

### F1.2 Drag-area budget grows with altitude; sea-level Mach 1 is not credible
- Allowable CD*S = Fn/q at M1: 44 cm2 (0 km), 52 (1 km), 66 (3 km), 86 (5 km), 122 (10 km)
  for the SLS-rated engine. A faired 150 mm-diameter body alone is ~35-55 cm2 at M ~ 1
  (Hoerner ch. 16-17). Hence D1.1 and D1.2.

### D1.1 "500 N" is defined at the Mach 1 dash point, not at SLS
- **Tool:** pyCycle, `prelim_design_point_options.py`, like-for-like cycle designs at SLS,
  M1/0 km, M1/3 km, M1/6 km, each re-run at the other points in both limit modes.
- **Numbers:** design at M1 / 5 km for 500 N -> airflow 1.120 kg/s (vs 0.865 for the SLS
  design), SLS thrust 665 N (RPM-limited), M1 thrust 551 / 523 / 500 N at 1 / 3 / 5 km.
- **Why:** the user's thrust is for drag at Mach 1; definition A leaves 65 % of the rating
  at the mission point. Cost: ~30 % more airflow -> engine mass, to be absorbed in Phase 2/4.
- Supersedes A0.1.

### D1.2 Mission profile: Mach 1 dash at 5 km ISA (candidate C of four)
- **Tool:** point-mass energy integration, `prelim_mission_energy.py`, on the D1.1 engine
  table; drag parameterised as 75 % of the thrust-limited CD*S with drag-rise factor 2
  (A1.2, A1.3), sensitivity over 0.6-0.9 and 1.5-3.0.
- **Numbers (1 / 3 / 5 / 10 km):** CD*S budget 88 / 107 / 132 / 156 cm2; q 62.9 / 49.1 /
  37.8 / 18.5 kPa; time to M1 18 / 24 / 31 / 61 s; sortie 60 / 166 / 273 / 553 s; fuel
  incl. reserve 0.82 / 1.10 / 1.40 / 2.09 kg; P3 at dash 558 / 475 / 401 / 216 kPa;
  compressor-inlet Re index 1.36 / 1.12 / 0.92 / 0.53.
- **Why 5 km:** fuel is never the discriminator (<10 % MTOW everywhere). 5 km gives the
  largest drag budget (132 cm2) and the lowest structural q (38 kPa) that still keeps the
  engine out of the low-P3 / low-Re regime of 10 km, with a sortie under 5 min. 3 km is
  the documented fallback (107 cm2) if a lower ceiling is imposed; the same engine covers it.

### A1.x assumptions registered (see `docs/phase1_requirements.md` section 5)
ISA day (A1.1); 25 % acceleration margin at the dash (A1.2); drag-rise 2.0 (A1.3); idle
fuel 10 % (A1.4); 2 min reserve (A1.5); life >= 10 hot cycles / 1 h (A1.6); paved 300 m
sea-level runway (A1.7); kerosene fuel (A1.8); refuel between sorties (A1.9); ground roll
deferred to Phase 2 (A1.10). Non-engineering prerequisite noted: airspace authorization
and telemetry/autopilot for a Mach 1 uncrewed flight at 5 km.

### Derived requirements handed forward
E1-E7 (engine) and A1-A5 (airframe) in `docs/phase1_requirements.md` section 4. The
single hardest one: **airframe CD*S <= 132 cm2 (target 99 cm2) at M 1.0 / 5 km**, to be
demonstrated in Phase 2 with a cited transonic drag build-up, because no surveyed tool
does transonic drag.

---

## Phase 2 — Constraint sizing, drag, mass budget (2026-09-13)

Full write-up: `docs/phase2_airframe.md`. All outputs regenerate with
`python scripts/phase2_airframe/run_phase2.py`.

### F2.0 External requirement: the Boom Prize (https://boomsupersonic.com/prize, read 2026-09-13)
The brief's mission (25 kg incl. fuel, Mach 1 held, two flights in one day, land) matches
the Boom Prize rules. Additional rules adopted as requirements: Mach 0.8 -> >1 level or
climbing with no altitude loss; >= 5 s continuous above Mach 1 by true airspeed;
reciprocal headings; wheeled OR belly landing, reflyable; human pilot with instant abort;
calibrated pitot-static + TAT + sealed loggers + GPS. No altitude limit is stated, so D1.2
stands. Eligibility on the page: US citizens / permanent residents, amateur teams.

### D2.0 Tools for Phase 2
- ADRpy (NumPy-1 env) for the constraint equations; bugs found: default quarter-chord sweep
  operator precedence (`constraintanalysis.py:392`, lift slope 1.23 vs 2.87/rad), turn uses
  climb weight fraction. Worked around, documented.
- AeroSandbox 4.2.10 added (verified helpers only); radius-form Sears-Haack function returns
  CD on frontal area despite docstring (39x off) -> not used.
- Own slender-body wave-drag integral, verified to 0.07 % (Sears-Haack) and exactly against
  an analytic parabolic-area body (0.9607).
- No surveyed tool does transonic drag -> Raymer build-up + area-rule wave drag, with the
  E_WD uncertainty carried as a 1.8 / 3.0 bracket.

### D2.1 Drag design point M 1.02 at 5 km
Holding M >= 1.00 for 5+ s with +-0.02 air-data uncertainty. The drag-rise fairing gives
0.49 (M 1.00) vs 0.71 (M 1.02) of the fully developed wave drag, so this is not a free
margin: dash drag at 1.02 is 16 % above M 1.00 (83.1 vs 71.8 cm2).

### D2.2-D2.6 Configuration shaping (numbers at S 0.30 m2, M 1.02 / 5 km)
- C1: body of revolution, sharp-lip nose pitot inlet, AR 3, taper 0.2, 5 % section,
  all-moving HT + fin (Raymer tail volume 0.40 / 0.07).
- Forebody 30 -> 40 % and LE sweep 45 -> 55 deg: 91 -> 73 cm2 (150 mm placeholder engine).
- D2.3 engine envelope from 26-engine database at 665 N SLS: 6.83 kg, 188 mm, 453 mm ->
  body 218 mm -> 97.5 cm2 at 2.4 m. D2.4 length 2.7 m, forebody 45 %: 91.6 cm2.
- D2.6 aft closure 22 -> 28 % + half-wing-area waist: 83.1 cm2 nominal, 100.5 cm2 at
  E_WD 3.0. A waist alone did nothing nominally (geometric E_WD 1.97 -> 2.84).
- Rejected: 60 deg sweep (-2 cm2 only, worse low-speed lift); 3.0 m body (-4 cm2 for
  +0.17 m2 wetted area and mass).

### D2.5 Landing: plain flaps + 0.6 m drag chute, wheeled
Constraint diagram: dash needs S <= 0.383 m2 (25 % margin, nominal, 25 kg); a 300 m runway
without a chute needs S >= 0.44 m2 (flaps) -> no overlap. At S 0.30 m2: flaps only 396 m,
flaps + chute 209 m, no-flap + chute 235 m (mu_brake 0.3). Chute +0.20 kg. Fallbacks:
>= 500 m runway (flaps, no chute) or belly landing (prize-legal).

### D2.7 Wing area S = 0.30 m2
S range 0.24-0.38 m2 from the dash margin. 0.30 m2: dash throttle 0.67 nominal / 0.81 at
E_WD 3 (50 % / 24 % margin), V_LOF 47 m/s at TOGW, landing 209 m with chute. 0.35 m2 drops
the pessimistic margin to 17 %; 0.25 m2 raises V_LOF to 51 m/s.

### D2.8 Mass budget closes: TOGW 18.7 kg (margin 6.3 kg); 21.4 kg (margin 3.6 kg) high-engine case
Engine 6.83 + accessories 1.60 + structure 3.84 + gear/chute 1.27 + fuel system 0.40 +
systems/instrumentation 2.02 + growth 1.13 + fuel 1.58. RC-jet statistics give 6.7 kg for
airframe + systems vs 7.5 kg bottom-up (8.7 with growth): the bottom-up value is used.

### F2.4 Mission with the drag polar (S 0.30 m2, 18.7 kg)
Brake release to M 1.02 at 5 km in 26 s; transonic pinch minimum excess thrust 167 N
nominal / 99 N pessimistic (level flight, prize-compliant); M 1.02 hold needs 328 / 396 N
of 492 N installed; sortie fuel 1.29 + 0.24 reserve (+3 % unusable) = 1.58 kg.

### F2.5 Engine diameter is a first-order airframe driver
+10 mm engine diameter -> +5.5 / +8 cm2 dash drag area (+20-30 N). 150 mm engine: -23 % /
-29 % dash drag. Carried into the Phase 3 architecture trade (centrifugal vs axial).

### F2.6 Flutter screening passes
NACA TN 4197 closed form: minimum V_f / V = 2.5 (wing) with 2+2 ply carbon skins; tails
3.6-5.9. Screening only; modal analysis in Phase 4/5.

### Process note
The background data-collection agent wrote an early 8-row engine table and a fit script
(12:43) before replacing the table with the final 26-engine version; the orphaned script
read the old columns and was rewritten (`engine_database_fit.py`). No committed file was
affected.

---

## Phase 3 — Engine cycle and architecture trade (2026-09-13)

Full write-up: `docs/phase3_engine.md`. User instruction: do not carry the Phase 2 catalog-fit
engine (6.83 kg / 188 mm); derive mass and diameter from a designed geometry. Done: no Phase 3
number uses the catalog fit.

### F3.1 Tool findings (ground rule 3)
- NASA turbo-design cannot predict axial-compressor efficiency: `loss/compressor/lieblein.py` is
  empty, OTAC classes are zero-returning placeholders, `DiffusionLoss` is an ad-hoc ramp.
- TurboDesigner: efficiency is an input; its rotor diffusion factor uses absolute velocities
  (0.03 vs 0.40 for the matched stator) -> recomputed; last stator `next_flow_station` asserts.
- TurboFlow turbine design optimisation: ignores the operating-point omega (85 000 rpm requested,
  104 000 returned) -> omega equality constraint added; has no structural constraint (optimum had a
  688 m/s tip, ~716 MPa blade-root stress) -> 350 MPa blade-root limit added as a tip-radius constraint.
- TurboFlow and the Howell model both predict component efficiencies far above what fielded
  engines achieve (next entry) -> two technology levels carried.
- Next-best method for the axial compressor: Howell cascade method (Saravanamuttoo ch. 5) + Re,
  tip-clearance and shock penalties on TurboDesigner triangles; verified at 0.90-0.92 row
  efficiency for conventional-scale cases.

### F3.2 Real-gas and calibration anchors
- Cantera vs pyCycle at the combustor exit: T4 -3.3 K (0.3 %), gamma +0.0002, cp +0.6 %.
- Vendor (W, PR, Fn, Wf) sets are inconsistent with vendor EGT limits (need T4 1330-1450 K) ->
  published airflows treated as nominal. Vendor SLS TSFC 0.145-0.167 kg/(N h) requires
  eta_c ~0.66-0.70, eta_t ~0.70-0.75. Phase 1 placeholder gave 0.110 (40 % optimistic).
- Fielded level adopted: eta_c 0.70 (centrifugal), eta_t 0.75, eta_b 0.95 (A3.1).

### D3.1 Dash design-point cycle
Fn 500 N at M 1.02 / 5 km, T4 1150 K (D1.1), convergent nozzle; intake inside the cycle:
normal shock 0.99998 + 1.32 m duct 3.3-3.4 % Pt loss (replaces A2.3). Burner dP/P 0.05, eta_b 0.95.

### F3.3 The combustor sets the diameter; pressure ratio shrinks it
Lefebvre theta scaling from 7 reference engines (theta_ref 7.24e7, log-sigma 0.20): at OPR 4 the
combustor OD is 163-170 mm, at OPR 5 136-143 mm, at OPR 6 117-125 mm. The architecture decides
how much pressure ratio is affordable within rotor stress limits.

### D3.2 Convergent nozzle kept
C-D nozzle gains 2 % (tool) / 0.2 % (fielded) thrust at NPR 2.8-3.7: not worth its mass.

### Architecture trade — both options side by side (dash, Fn 500 N, T4 1150 K)

Engine mass = bottom-up geometry/materials model x 1.24 validation factor (F3.6).

| | Centrifugal, 1 stage, OPR 4, 85 000 rpm | Axial, 5 stages, OPR 5, 65 000 rpm (turbine inside casing) |
|---|---|---|
| compressor tool used | TurboFlow (Oh losses) | TurboDesigner geometry + Howell loss model |
| stage count | 1 compressor stage + 1 turbine stage | 5 compressor stages (253 blades) + 1 turbine stage |
| compressor efficiency, tool / fielded | 0.794 / 0.70 | 0.841 / 0.741 |
| turbine efficiency, tool / fielded | 0.935 / 0.75 | 0.925 / 0.75 |
| airflow, tool / fielded | 1.084 / 1.326 kg/s | 1.052 / 1.293 kg/s |
| **outer diameter, tool / fielded** | **163 / 175 mm** | **136 / 151 mm** |
| diameter set by | combustor / compressor diffuser | combustor + turbine / turbine + compressor |
| length (calibrated), tool / fielded | 444 / 474 mm | 615 / 663 mm |
| **engine dry mass, calibrated, tool / fielded** | **5.52 / 6.57 kg** (fielded range 6.15-6.94) | **5.96 / 7.28 kg** (fielded range 6.81-7.69) |
| dash drag nominal / pessimistic (fielded) | 296 / 348 N | 253 / 282 N |
| **thrust margin nominal / pessimistic, tool** | **+83 % / +60 %** | **+109 % / +97 %** |
| **thrust margin nominal / pessimistic, fielded** | **+69 % / +44 %** | **+98 % / +77 %** |
| 25 % target | holds in all four cases | holds in all four cases |
| worst corner (eta_c 0.66, combustor +1 sigma, E_WD 3) | +32 % | +61 % |
| TOGW (calibrated), fielded | 18.6 kg | 18.9 kg (19.6 at equal compressor efficiency) |
| rotor stress | impeller 464 MPa (tool) -> 526 MPa (fielded) vs 450 allowable | within allowables by construction |
| modelling confidence | chain validated on 2 real centrifugal engines | axial efficiency unvalidated at this scale; operability unquantified |

Also evaluated and rejected: centrifugal 75 000 rpm (fielded pessimistic margin 18 %),
centrifugal OPR 5 (impeller 548 MPa; fielded pessimistic 19 %), axial OPR 4 at 55 000 rpm
(turbine-set 183 mm, 7.7 kg raw fielded), axial OPR 6 uncapped (193 mm, pessimistic 21 %),
axial OPR 6 capped (155 mm, +93 % / +72 %, but 7 stages and 720 mm long).

### F3.4 Centrifugal impeller stress is the conditional in its pass
Same PR at lower efficiency needs more tip speed: 504 -> 537 m/s. If limited to its tool-level
tip speed, fielded PR falls to 3.48, the combustor grows to 190 mm and the pessimistic margin
drops to 24 %.

### F3.5 Transonic acceleration is not binding
Centrifugal fielded deck (placeholder maps): excess thrust +259 % at M 0.70, +150 % at M 0.95;
the minimum is the M 1.02 dash point.

### F3.6 Mass-model validation
JetCat P400-PRO: 3.45 vs 4.01 kg (-14 %), 319 vs 390 mm, 145 vs 148 mm. AMT Nike: 6.98 vs 9.15 kg
(-24 %), 430 vs 524 mm, 203 vs 201 mm. Calibration x1.24 mass (1.16-1.31), x1.22 length.

### D3.3 Recommendation: axial, 5 stages, OPR 5, 65 000 rpm, turbine inside the casing
Why, with numbers: fielded margin +98 % / +77 % vs +69 % / +44 %; worst corner +61 % vs +32 %;
151 vs 175 mm; no stress allowable exceeded (the centrifugal needs its impeller qualified ~17 %
above the conceptual allowable, otherwise 24 % margin); cost +0.71 kg engine, +0.3 kg TOGW.
Against it: +190 mm length, 253 blades down to 10 mm chord, unvalidated efficiency model,
unquantified part-speed stall and start behaviour, no sub-1 kN all-axial precedent.
Fallback: centrifugal OPR 4 / 85 000 rpm if its impeller clears ~530 MPa in Phase 4 FE.
Phase 4 not started, as instructed.

---

## Phase 3b — Axial-centrifugal option, evaluated before Phase 4 (2026-09-13)

User request: evaluate 1-2 axial stages + 1 centrifugal stage with the same tools and the same
stress allowable as the pure centrifugal; state whether it closes the impeller-stress problem
while staying shorter than the 5-stage axial. Write-up: `docs/phase3_engine.md` section 13.

### Method (unchanged from Phase 3)
Axial stages: TurboDesigner + Howell loss model. **The Phase 3 caveat applies unchanged:**
textbook method verified only at conventional scale, not validated at micro scale, with the
fielded debit assumed (A3.4); the front stage is transonic (tip M_rel ~1.30). Centrifugal stage:
TurboFlow with identical settings. Turbine: TurboFlow, stress-limited and envelope-capped.
Combustor: theta-scaled. Mass: bottom-up x 1.24 (P400 / Nike calibration). Impeller allowable:
450 MPa Ti-6Al-4V solid-disc, as for the pure centrifugal. Not modelled: transition-duct loss,
residual swirl at the impeller eye.

### F3b.1 The front axial stage caps the spool speed at ~70 000 rpm
Same limits as the pure axial (tip M_rel <= 1.35, hub/tip >= 0.40): feasible to 70 000 rpm
(M_rel 1.33-1.34), infeasible from 72 000 rpm (1.36). 68 000 rpm used. No feasible front stage at
75 000 or 85 000 rpm in the screening.

### F3b.2 Impeller load and stress by split (screening at 65 000 rpm, W 1.08 kg/s)
| front stages | axial PR | OPR | impeller PR | U2 tool / fielded | Ti stress factor tool / fielded |
|---|---|---|---|---|---|
| 1 | 1.5 | 4.0 | 2.67 | 421 / 452 m/s | 1.39 / 1.20 |
| 1 | 1.5 | 4.5 | 3.00 | 448 / 481 | 1.23 / 1.07 |
| 1 | 1.3-1.5 | 5.0 | 3.85-3.33 | 494-471 / 529-506 | 1.01-1.11 / 0.88-0.96 (fails fielded) |
| 2 | 2.0 | 4.0 | 2.00 | 364 / 393 | 1.86 / 1.60 |
| 2 | 2.0 | 5.0 | 2.50 | 421 / 454 | 1.39 / 1.19 |
| pure centrifugal | - | 4.0 | 4.00 | 504 / 537 (85k) | 0.97 / 0.86 |

### Comparison (fielded level; tool level in `data/phase3_arch_trade_summary.csv`)
| | Centrifugal OPR 4 85k | Axial 5-st OPR 5 65k | AC 1ax OPR 4 68k | AC 1ax OPR 4.5 68k | AC 2ax OPR 4 68k | AC 2ax OPR 5 68k |
|---|---|---|---|---|---|---|
| OD (set by) | 175 (diffuser) | 151 (turbine) | 182 (diffuser) | 195 (diffuser) | 169 (combustor) | 185 (diffuser) |
| length, calibrated | 474 mm | 663 | 641 | 632 | 704 | 680 |
| dry mass, calibrated | 6.57 kg | 7.28 | 8.73 | 9.17 | 8.90 | 9.51 |
| drag nom / pess | 296 / 348 N | 253 / 282 | 312 / 373 | 344 / 422 | 285 / 331 | 320 / 385 |
| margin nom / pess | +69 / +44 % | +98 / +77 % | +60 / +34 % | +45 / **+19 %** | +75 / +51 % | +56 / +30 % |
| worst corner | +32 % | +61 % | +23 % | - | +32 % | +15 % |
| impeller stress factor | 0.86 | - | 1.20 | 1.06 | 1.58 | 1.19 |
| TOGW, calibrated | 18.6 kg | 18.9 | 20.8 | 21.3 | 20.8 | 21.5 |

### D3b.1 Verdict
It closes the impeller-stress problem (every variant >= 1.06 fielded), but it does NOT stay shorter
than the 5-stage axial (632-704 vs 663 mm), it is the heaviest option (+2.2 to +2.9 kg over the pure
centrifugal), and only its 2-axial-stage OPR-4 variant improves on the centrifugal's margin
(+51 % vs +44 % pessimistic; worst corner equal at +32 %). The 1-stage OPR-4.5 and 2-stage OPR-5
variants fail the 25 % pessimistic target. Mechanism: the front stage limits the shaft to
~70 000 rpm, so the impeller, diffuser and turbine disc grow, and the diffuser sets the diameter.
**It relocates the risk (to mass, diameter and the unvalidated axial stages) rather than removing it.**
Recommendation unchanged (pure axial OPR 5). New order of fallbacks: AC 2 axial + cc at OPR 4
(stress-safe, +51 % margin, 8.9 kg), then the pure centrifugal if its impeller is qualified at
~530 MPa (lightest and shortest). Phase 4 not started.

---

## Phase 4 entry gate: impeller stress check, pure centrifugal at 537 m/s (2026-09-13)

User request: a fast, cheap decision gate. Run a detailed stress check of the pure-centrifugal
impeller (OPR 4, 85 000 rpm, fielded U2 537 m/s), covering the blade root and disc burst, and
report the real margin at about 530 MPa. If it passes, flag the centrifugal as likely preferred.
If it fails, proceed with Phase 4 on the pure axial. Write-up: `docs/phase4_impeller_stress_gate.md`.

### D4.0 Tool: scikit-fem 12.0.2 (added to `.venv`), verified before use
Axisymmetric rotating-body FE (`axisym_fe.py`, P2 triangles, centrifugal + traction + thermal)
checked against Timoshenko & Goodier closed forms:
* solid disc: centre +0.00 %, rim +0.35 %
* bored disc: bore -0.44 %
* parabolic-temperature disc: centre -0.02 %, rim -0.35 %

Morley-element Kirchhoff plate for the exducer blade: +5 % over cantilever theory (conservative).
No approved tool does 3D solid FE of a bladed impeller, so 3D effects such as rake and lean are
out of scope.

### Inputs (sourced)
* Material: Ti-6Al-4V at about 250 C, from the ATI Grade 5 data sheet typical curves (Fty ~100 ksi,
  Ftu ~111 ksi at 480 F; E 98 GPa; CTE 9.2e-6 /K), scaled to a minimum basis by the AMS 4928
  minimum/typical ratios: Fty 620, Ftu 681 MPa.
* Burst: 14 CFR 33.27 (120 % speed, 5 min, no burst), so N_burst/N >= 1.2 by the Robinson
  average-hoop criterion with k 0.85.
* Blade/hub fillet: Kt 1.4 (Peterson).
* Thermal field: eye 309 K to exit 520 K, from the Phase 3 fielded dash cycle.

### F4.0 Results
| part | result | status |
|---|---|---|
| hub with 12 mm through-bore, best shape (boss A 18 mm, p 2) | 529 MPa (+18 % yield margin); with thermal 580-601 MPa (+3.5 to +7 %) | marginal |
| hub boreless, same shape | 304 MPa; with thermal 319-326 MPa (+90 %) | pass |
| burst | N_burst/N 1.71 (bored), 1.92 (boreless), required >= 1.2 | pass |
| exducer blade root, 30 deg backsweep, Kt 1.4 | 1016 / 656 / 421 MPa at 2.5 / 3.5 / 5 mm root; passes only at >= 5 mm, with 32 % root blockage (5 % assumed in the aero design) | **fail** |
| inducer blade root tension | 220 MPa | pass |

Blade sensitivity at a 3.5 mm root:
* backsweep 20 deg: 444 MPa
* backsweep 10 deg: 224 MPa
* backsweep starting at 0.85 r2 instead of 0.7 r2: 517 MPa

The aero side of any of these is not evaluated.

### D4.1 Verdict: the impeller as designed FAILS the stress check (blade root, not disc)
The disc passes if boreless, and burst passes. The backswept exducer blade root fails at every
aerodynamically acceptable thickness. Per the user's instruction, **Phase 4 proceeds on the pure
axial (5 stages, OPR 5, 65 000 rpm, capped turbine)**, starting with low-speed operability and
stall, then shaft dynamics.

The centrifugal is not ruled out in principle. A redesigned exducer (about 20 deg backsweep or
tip-concentrated backsweep, boreless hub) would likely pass the stress check. But it needs a new
aero design, cycle point and a 3D FE check, which is outside this gate and is the user's decision.

**Open risk carried forward (R4.1):** the axial-stage efficiency comes from the Howell cascade
method, which has been checked only at conventional scale. Revisit it with a micro-axial validation
source if one becomes available, for example published micro-axial compressor test data.

---

## Phase 4 — axial compressor input error found and corrected (2026-09-13)

### F4.2 Phase 3 error: TurboDesigner blockage input doubled every axial annulus area
**The error.** `axial_design.build` passed `inlet_blockage=0.98 / outlet_blockage=0.96`, intended
as effective/physical area ratios. TurboDesigner 2.0.0 computes
`physical_area = flow_area * (1 + blockage)` (`flow_station.py`), and its README example uses 0.0.
So the Phase 3 axial annuli were 1.96-1.98 x too large.

**How it was found.** The Phase 4 stage-stacking model needed effective/geometric area 0.52 to
reproduce the design axial velocity. Evidence: `check_turbodesigner_blockage.py` (inlet tip radius
63.8 mm with the old input vs 45.8 mm with the corrected one).

**Effect.** The velocity triangles and loss-model efficiency were consistent. Radii, blade heights,
the turbine envelope cap, spool-speed feasibility and masses were not. The pure axial and the
axial stages of the axial-centrifugal are affected; the centrifugal and the impeller gate are not.

### D4.2 Correction and re-run
**Fix.** Blockage input set to 0.02 / 0.04 (the intended 2 % / 4 %).

**Re-run.** The trade was re-run with unchanged method, limits and calibrations:
* the rpm grid was extended to 90k;
* fixed-rpm cases were added (75k / 80k / 85k), because compressor efficiency is flat in rpm;
* 60k and 70k turned out infeasible (last blade height / DF).

**Corrected results, fielded, calibrated:**

| case | OD | length | dry mass | margin nom / pess |
|---|---|---|---|---|
| **axial OPR 5, 6 stages, 80k (new baseline)** | 142 mm, combustor-set | 611 mm | 5.74 kg | +104 / +89 % (worst corner +71 %) |
| was: 5 stages, 65k | 151 mm | 663 mm | 7.28 kg | +98 / +77 % (worst +61 %) |
| axial OPR 4 | 169 mm | 689 mm | 6.99 kg | +76 / +52 % |
| axial OPR 6 | infeasible with <= 7 stages | | | |
| AC 2 axial + cc, 90k | 170 mm | 610 mm | 6.11 kg | +75 / +50 % |
| AC 1 axial + cc, 90k | 170 mm | 564 mm | 6.14 kg | +75 / +50 % |

The AC front-stage speed limit is now 95-100k, not ~70k. The Phase 3b mechanism was an artifact.

**Decision.** The Phase 3 recommendation (pure axial, OPR 5) stands and is strengthened; the
baseline becomes 6 stages at 80 000 rpm. The fallback order becomes AC (90k), then the pure
centrifugal (not qualified as designed). Written up in `docs/phase3_engine.md` section 14, with a
banner at the top of that doc.

**Tool defect logged (TurboFlow 0.1.18, performance analysis):**
* With `stop_on_failure=False`, a failed point leaves None in the timing list and
  `print_simulation_summary` crashes; worked around by disabling that summary.
* After a failed point, every later point in the same call fails ("'list' object has no attribute
  'keys'", because the failed solution is used as the next initial guess). Worked around by sweeping
  each speed line outward from the design pressure ratio in two calls.

---

## Phase 4 — low-speed operability and stall of the pure axial (2026-09-14)

Write-up: `docs/phase4_operability.md`. Plot: `plots/phase4_operability.png`.

### D4.3 Tools and models (no approved tool gives axial maps)

**Compressor map:** own mean-line stage-stacking model, `axial_offdesign.py`. It extends the Phase 3
Howell design model:
* frozen geometry, constant deviation, fixed IGV (implied by the 50 %-reaction design);
* loss parabola calibrated to the Phase 3 stage efficiencies;
* stall at Howell's stalling deflection eps_s = eps*/0.8, with nominal
  tan(in*) - tan(out*) = 1.55/(1 + 1.5 s/c) (*Gas Turbine Theory*, ch. 5);
* surge surrogate = the peak of each speed line.

Verified: design point reproduced (PR 5.031 vs 5.000, eta 0.831 vs 0.828). Not validated
(open risk R4.1).

**Turbine map:** TurboFlow performance analysis of the Phase 3 turbine geometry (`turbine_map.py`).
The design point is reproduced exactly (1.077 kg/s, eta_tt 0.9306). Two TurboFlow defects were
worked around (F4.2).

**Engine match:** pyCycle with both maps (`operability.py`). Added to `cycle_model.py`, all default
off, with Phase 3 results re-checked unchanged (centrifugal dash W 1.32575 kg/s, TSFC 0.16416):
* map options;
* nozzle-area scale;
* overboard bleed port;
* transient mode NT4.

**Surge-margin criterion:** about 20 % for an HP compressor and 15 % for an LP one, up to half of it
for transients, defined as dR/R (Rolls-Royce patent CN112081683A).

**Bracket:** the same match with pyCycle's NPSS AXI5 map (5-stage PR 5.2 axial; provenance
undocumented).

### F4.3 Results (fixed geometry, dash-sized convergent nozzle)
* **Design point (dash):** surge margin 14 % at constant speed (18 % at constant flow), short of
  about 20 %. At the dash the nozzle stays choked and SMN stays at 13-15 % down to 70 % speed, but
  the first rotor passes its Howell stalling deflection below about 87 % corrected speed.
* **SLS:** the nozzle is unchoked (NPR at or below 1.65). SMN falls from 12 % at 100 % to 2.5 % at
  85 %, and the running line meets the peak line at about 83 %, below which there is no steady
  match. The first rotor is stalled from about 87 %. At 100 % SLS, T4 is 1163 K, so the speed limit
  sits at about 99 % for about 680 N.
* **AXI5 bracket:** stall-free to about 55 % (SMN 20-27 % over 70-95 %), meeting the stall line at
  about 52 %.
* **Remedies on the stacking map, singly:**

  | remedy | lowest steady speed | penalty |
  |---|---|---|
  | variable IGV (21 -> 49 deg) | about 80 % | stator 1 stalls |
  | nozzle x1.3 to x2 | about 80 % | costs 220-410 N of SLS thrust if left open |
  | 20 % bleed after stage 3 | about 70 % | - |
  | 30 % bleed | about 65 % | T4 up to 1250 K, over the limit |

* **No configuration reaches a conventional 30-35 % idle.** Acceleration time was not computed:
  there is no idle, and the steady SLS margin at 85-95 % is below the roughly 10 % transient
  allowance.

### D4.4 Verdict and decision point (not taken autonomously)
The Phase 3 "operability not quantified" risk of the pure axial is real. A workable pure axial would
need combined variable geometry and bleed (VIGV + start bleed + probably a variable nozzle), and
still idles at or above about 55-65 %.

Recommendation to the user: before more Phase 4 work on the pure axial, run the same two cheap checks
on the corrected axial-centrifugal (1-2 axial stages + cc, 90 000 rpm; 6.1 kg, +75 / +50 %):
1. impeller exducer blade root at 409-471 m/s;
2. operability with the TurboFlow centrifugal map.

Options A (pure axial with variable geometry), B (AC) and C (redesigned centrifugal) are laid out in
`docs/phase4_operability.md` section 3. Phase 4 mechanical design and CAD have not been started.

**Open risk R4.1 (carried, as instructed):** axial-stage efficiency and off-design loss/stall
correlations are checked only at conventional scale. Revisit them with published micro-axial
compressor test data. The AXI5 bracket shows the low-speed answer is map-sensitive.

---

## Phase 4 — rotor dynamics of the pure axial (2026-09-14)

Write-up: `docs/phase4_rotordynamics.md`. Done by a parallel sub-task on the corrected geometry.
Its assumed idle (35 %) is superseded by the operability result: idle at or above 55-65 %, which
means the damped 36 krpm mode is crossed only during start and shut-down.

### D4.R1 Tool: ROSS 2.3.0 (ross-rotordynamics, PyPI, added to `.venv`), verified before use
It was installed with uv. It added packages only; no existing package changed version. The new
packages include ross-rotordynamics 2.3.0, numba 0.67.0, ccp-performance 0.4.1, pint, control and
scikit-learn; refreeze `requirements-np2.txt`.

Two import work-arounds are in `scripts/phase4_turbomachinery/ross_shim.py`. Neither affects the
FE matrices:
* plotly 7 removed the `scattermapbox` template key, so the ROSS theme is created with skip_invalid;
* numba 0.67 cannot type ROSS's orbit helper, so it runs with `NUMBA_DISABLE_JIT=1`.

Verification (`rotordynamics_verify.py`) against closed forms:

| case | error |
|---|---|
| simply supported shaft, Euler-Bernoulli | -0.0001 % (Timoshenko -0.30 %) |
| Jeffcott rotor | -0.0001 % |
| overhung disc with gyroscopics, 0-60 krpm, forward and backward whirl | -0.13 to -0.20 % |
| project lateral eigen-solver vs ROSS run_modal | 0.000 %, same whirl labels |
| forward synchronous critical | -0.19 % |
| damped solver vs single-DOF k-c | +0.003 % frequency, -0.006 % damping ratio |

Mesh convergence: 10 mm → 5 mm changes the criticals by at most 0.04 %.

### Inputs (sourced)
* **Geometry and masses** from the corrected trade
  `data/phase3/trade_ax0_opr5_t1150_cap_blk_fielded.json` (6 stages, 80 000 rpm), through
  `arch_trade.scaled_comp` + `engine_mass`. The model reproduces the engine_mass disc and blade
  masses exactly (`rotor_model.py`). An earlier scratch run on the superseded pre-blockage-fix
  geometry was discarded.
* **Bearing and support stiffness:**
  * 1.9e7 N/m: 10 x 26 mm angular-contact ball bearing at 63 krpm (Wang, Lv & Luo, *Sensors* 2023);
  * 4.4e7 N/m: ball bearing on rigid supports (Gunter 2023);
  * 1.75e6 N/m and 876 N s/m: optimum damper cartridge of a ball-bearing turbocharger (Gunter 2023);
  * 6e5 N/m: micro gas turbine bearing suspension (ASME JEGTP 146(10) 101002, 2024).
* **Criteria:** API 684 (2003) statement of the API 617 AF-dependent separation margins (AF < 2.5
  none; 2.5-3.55: 15 % / 5 %; > 3.55: formulas capped at 26 % above MCS and 16 % below minimum
  speed). MCS = 105 % = 84 000 rpm; idle 35 % = 28 000 rpm.
* **Support damping in jet engines:** San Andrés, TAMU Notes 13 (2010), squeeze-film dampers with
  rolling bearings.

### F4.R1 The rotor as mass-sized in Phase 3 is not dynamically acceptable
The Phase 3 rotor has a 16/8 mm shaft and a 0.32 mm drum (the tie allowance). Layout A is the
front bearing at the compressor inlet hub and the rear bearing under the NGV, span 409 mm, turbine
overhang 20 mm. Its forward criticals:

| support stiffness | criticals |
|---|---|
| 1.9e7 N/m | 11.9 / 40.0 / 57.0 / 99.8 krpm |
| 1.75e6 N/m | 10.7 / 14.1 / 35.4 / 76.4 krpm |

Bending modes fall inside 28-84 krpm at every stiffness from 6e5 to 1e9 N/m, and in the damped
check at every damping level up to 2000 N s/m. Layout B (both bearings in the tunnel, 181 mm
compressor overhang) is similar or worse.

### F4.R2 Neither hard bearings nor a stiffer rotor alone can fix it
* **Hard bearings (1.9e7 N/m):** a bearing-dominated mode sits at 40-41 krpm for any shaft of
  16-32 mm OD and any drum of 0.3-3 mm.
* **Soft supports:** the free-free bending mode of the 0.43 m rotor stays at 23-53 krpm, against the
  106 krpm (MCS + 26 %) target. The shaft OD is capped at about 24 mm by the 14 mm-radius tunnel
  inside the combustor hub (Ri 17.4 mm).

### F4.R3 Soft, damped supports plus a stiffened rotor pass the API AF rules
Configuration: layout A, 2 mm Ti drum, 24/12 mm shaft with 16 mm journals, k 1.75e6 N/m,
c 876 N s/m. Damped criticals:

| critical | AF | where |
|---|---|---|
| 11.1 krpm | 1.9 | below idle |
| 17.9 krpm | 1.8 | below idle |
| 35.6 krpm | 1.1 | inside the range, critically damped |
| 120.0 krpm | 6.2 | 43 % above MCS |

It passes over k 0.6-5e6 N/m with c 876-2000 N s/m. Layout B passes only at c 2000 N s/m.

### D4.R2 Rotor-dynamic recommendation (screening)
* Layout A.
* Squeeze-film or O-ring damper cartridges at both ball bearings, k about 1-2e6 N/m and c about
  900-2000 N s/m. Hard-mounted bearings are ruled out.
* Stiffen the rotor beyond the Phase 3 mass sizing: 2 mm drum, 24/12 mm shaft, 16 mm journals.
  This costs **+0.53 kg of rotor mass (uncalibrated)**, taking the rotor from 1.39 to 1.91 kg.

Numbers for the transient work:

| quantity | value |
|---|---|
| **Ip** | **1.12e-3 kg m²** (9.31e-4 kg m² as mass-sized) |
| static bearing loads, 1 g | 6.2 / 12.5 N |
| gyroscopic bearing load | 23 N per rad/s of pitch or yaw rate (38-46 N per rad/s in layout B) |

### Open rotor-dynamic risks
* **R4.R1 Damper dependence.** The design relies on the dampers to make the free-free bending mode
  at about 36 krpm (45 % speed) critically damped. Damper realisation, temperature and nonlinearity
  are not modelled; neither are the damped unbalance response and the aero cross-coupling stability.
* **R4.R2 Bearing speed.** 16 mm journals at 80 krpm give DN 1.28e6, above the references (micro
  gas turbine DN 1e6; Wang bearing about 0.7e6).
* **R4.R3 Drum stiffness.** The drum is modelled as a continuous shell; joint flexibility
  (tie-bolt or curvic) is ignored, which is optimistic.
* The 85 000 rpm variant was not analysed.

---

## Phase 4 — option B checks: axial-centrifugal impeller stress and operability (2026-09-14)

User request: run the two checks proposed for option B. Write-up: `docs/phase4_optionB_checks.md`.
Plot: `plots/phase4_optionB_operability.png`.

### D4.5 Method (unchanged from options A / C, plus a benchmark)
**Check 1.** The gate solvers and criteria were applied to both AC impellers (`impeller_check_ac.py`):
* Phase 3 TurboFlow geometry, scaled to the fielded engine, at 90 000 rpm;
* tip speed 419 / 486 m/s.

**Check 2.** Combined compressor model (`ac_offdesign.py`):
* front stage(s) from the stage-stacking model;
* impeller from a TurboFlow off-design map (`centrifugal_map.py`, 10 x 21 points; design runs reproduced exactly);
* TurboFlow turbine maps and pyCycle running lines (`ac_operability.py`).

**Method benchmark** (`cc_benchmark.py`): the unchanged chain applied to the Phase 3 model of the JetCat
P400-PRO-LN, which idles at 30 000 rpm / 31 %, 14 N (database, jetcat.de).

### F4.5 Results
**Check 1: exducer blade root fails**, worse than the pure centrifugal:

| variant | root stress at 3.5 mm (limit 620) | root needed for Fty | hub blockage at that root |
|---|---|---|---|
| 2 ax + cc | 1105 MPa | 5.8 mm | 49 % |
| 1 ax + cc | 936 MPa | 4.9 mm | 36 % |
| pure centrifugal (for comparison) | 656 MPa | 3.7 mm | 23 % |

* Cause: tall exit blades, b2/r2 0.43 / 0.30 against 0.19.
* The disc and burst pass easily: boreless 208-276 MPa with the thermal gradient, burst ratio 2.1-2.4.
* About 10 deg of backsweep would pass (320-377 MPa); not evaluated aerodynamically.

**Check 2: operability no better than the pure axial.**
* Design-point SMN 11 %.
* SLS steady running line meets the surge surrogate at about 90 % speed.
* At 100 % SLS, T4 is about 1185 K (ECU limit about 97-98 %).
* Dash: 10-21 % margin over 70-100 %, once the impeller throat is opened (area ratio 0.65 -> 0.80). Phase 3 had
  sized it "just unchoked", leaving zero choke margin. TurboFlow PR and efficiency are unchanged by it.
* Robust to doubling the axial loss width.
* The combined peak is set by the axial stage(s): axial PR peaks 5 % below design flow and collapses 3 % above;
  the impeller characteristic is flat.

**Benchmark:**
* the chain predicts the P400 runs steady down to 35 % speed (27 N, EGT 740 C inside the published 480-750 C
  range), with 38-53 % surge margin, losing the match just below about 34 % (published idle 31 %);
* the rest of the chain is sound for centrifugal machines, so the decisive, unvalidated element in options A and B
  is the axial-stage model (R4.1).

**Correction.** The impeller gate said the pure-centrifugal root "survives at 5 mm or more (32 %)". The interpolated
threshold is 3.7 mm (23 % hub blockage, no margin). The gate doc is corrected; the verdict is unchanged.

### D4.6 Verdict
**Option B fails both checks as designed.** It does not cure the impeller problem it was meant to cure: the disc
passes but the blade root is worse. In the same model its operability is no better than the pure axial.

The pure centrifugal (option C) is the only architecture the benchmarked chain supports at low speed, and its only
failed item is the exducer blade root.

**Suggested next step (awaiting the user):** redesign the pure-centrifugal exducer, with about 10-20 deg backsweep
or tip-concentrated backsweep, then:
1. re-run the TurboFlow design, dash cycle and thrust margin;
2. run the stress gate and this operability chain on it.

Phase 4 mechanical design and CAD have not been started.

---

## Phase 3R — engine redesigned around a centrifugal compressor (2026-09-14)

Write-up: `docs/phase3r_centrifugal.md`. Plots: `plots/phase3r_cc_trade.png`, `phase3r_backsweep.png`,
`phase3r_mission.png`. Data: `data/phase3r/`, `data/phase3r_*`.

### D3R.0 User decision: centrifugal compressor only
The user decided to design the engine around a centrifugal compressor as the configuration suited to this scale, and
asked to go back to Phase 3 with the brief in view. Phase 3 was redone to the brief's Phase 3 scope:
* cycle at the reference point;
* a quantitative trade of 2-3 options with SFC, airflow, mass and size (here OPR, spool speed and backsweep of the
  single-stage centrifugal engine);
* off-design across the mission;
* one recommendation.

Phase 4 not started.

### F3R.1 Tool defect: TurboFlow 0.1.18 Wiesner slip takes cos(degrees) as radians
`centrifugal_compressor/slip_model.py`: `np.sqrt(np.cos(theta_out))`, while `theta_out` is in degrees everywhere else.
* **Evidence** (`verify_turboflow_slip.py`): the slip factor solved on the Phase 3 impeller is 0.9310 against the correct
  0.8366 at -30 deg; at -10 deg the model returns NaN.
* **Consequence:** the Phase 3 impeller gives PR 3.39, not 4.01, at 504 m/s. At the upstream example's -24.5 deg the
  error is only 6 %, which is why Phase 0 passed.
* **Fix:** `turboflow_fixes.py`, imported by `centrifugal_design.py` and `centrifugal_map.py`. The solved σ now equals
  Wiesner exactly.
* **Scope:** every earlier centrifugal result, including the Phase 3b and Phase 4 axial-centrifugal impellers, the gate
  and the P400 / Nike runs.

### F3R.2 The Phase 3 inducer was beyond fielded practice
`inducer_anchor.py`, with the same optimum-inducer rule on 9 database engines: inducer shroud relative Mach 1.10-1.33
(TJ40-G1 highest). At the fielded airflow, 85 000 rpm gives 1.43; 75 000 gives 1.29; 77 500 gives 1.33.
**A3R.1:** M1s,rel <= 1.33 → design speed 75 000 rpm.

### F3R.3 Fielded scaling was wrong for the impeller and unsafe for the turbine
* The √W scaling (A3.6) grew the impeller exit radius with flow, although work sets it. Work-based scaling is used
  instead: -6 to -8 mm where the diffuser sets the OD.
* The √W-scaled turbine tip was about 11 % past its 350 MPa blade-root limit, about 24 % in stress (Phase 3 centrifugal
  included). The turbine is now re-designed by TurboFlow at the fielded cycle: it sits on the limit, and mass drops
  about 0.7 kg.
* At 85 000 rpm the fielded turbine cannot pass the flow within the limit.

### F3R.4 Calibrations re-anchored with the fix
* **Mass model:** P400 3.52 vs 4.01 kg (-12 %); Nike 7.23 vs 9.15 kg (-21 %). Mass ×1.20 (1.14-1.27), length ×1.21.
  The Nike's compressor-set OD is over-predicted (212 vs 201 mm, +5.7 %), so the diffuser rule is conservative.
* **P400 operability benchmark:** steady to 37.5 % against the published 31 % idle (about 5 points pessimistic); design
  SMN 61 %.

### D3R.1 Method: stress inside the design loop
`impeller_stress.py` wraps the verified gate solvers. At MCS 105 %:
* the exducer root thickness is sized to Fty (Kt 1.4, >= 1.6 mm) and its blockage sets the physical exit width;
* boreless disc with the thermal gradient <= Fty;
* burst >= 1.2 × N_MCS.

Other conventions: 12 + 12 splitters (Aungier Z_eff 18), 10 % choke margin, trailing-edge dump loss checked
(<= 0.14 points).

### F3R.5 Trade (13 full-chain cases after the 36-design screen; fielded)
* **OPR:** optimum 4.0 at 75k, where the combustor (170 mm) and the diffuser meet.
* **Backsweep:** from 0 to -30 deg, OD 177 → 199 mm and pessimistic margin +41 → +14 %.
* **Stress:** every case is feasible once the root is sized.
* **77.5k radial:** 172 mm, +48 %, at the inducer limit.
* **85k:** looks best on paper (170 mm, +51 %) but violates A3R.1 and the turbine flow / stress limit.

### F3R.6 Backsweep sets the stability (TurboFlow maps + pyCycle, benchmarked chain)
Design surge margin is 0 / 19 / 28 / 39 % at 0 / -10 / -15 / -20 deg.
* **Radial:** radial blades give work independent of flow, so the characteristic peaks at the design point. The
  running line rides the surge surrogate: not operable.
* **-10 deg:** the SLS line has 12-17 % surge margin, and the engine cannot run steadily below 45 % speed.
* **Criteria:** SMN >= ~20 % needs >= 10.5 deg of backsweep; the 25 % pessimistic thrust margin needs <= 19 deg.

### D3R.2 Recommendation: single-stage centrifugal, OPR 4.0, 75 000 rpm, -15 deg backsweep
Chosen because it sits mid-window on both criteria.

| quantity | fielded | tool |
|---|---|---|
| airflow | 1.326 kg/s | 1.068 kg/s |
| dash TSFC | 0.164 kg/(N h) | 0.138 |
| impeller tip speed | 525 m/s (root 2.2 mm, blockage 9 %) | |
| engine OD | **187 mm**, diffuser-set | 173 mm |
| length / dry mass | **478 mm / 6.74 kg** (6.38-7.09) | 6.21 kg |
| margin nom / pess | **+55 / +29 %** (worst corner +22 %) | +71 / +46 % |
| design surge margin | 28 %; SLS line 22-27 % over 55-100 % | |
| SLS max thrust | 631 N at 98.2 % speed, T4-limited | |
| lowest steady speed / idle for fuel | 35 % / 40 % (37 N, 19 % of max fuel) | |

Impeller disc +86 % yield margin, burst ratio 1.90 at MCS.

**Cantera:** T4 -4 K, γ +0.0002 against pyCycle.

**Sensitivities:**
* OD calibrated to the Nike: 177 mm, +42 %;
* η_c 0.66: 192 mm, +22 %;
* η_c 0.74: 182 mm, +35 %.

Against the Phase 3 centrifugal claim (175 mm, +44 %): 12 mm larger and 15 points lower, because the Phase 3 numbers
were not achievable (F3R.1-F3R.3, plus the gate).

### F3R.7 Mission with the real-map deck (replaces the placeholder maps, A3.8)
* The deck is T4-limited at low Mach; 500 N at the dash point.
* Brake release to M 1.02 / 5 km in 28 s. Minimum transonic excess thrust 115 N (pessimistic drag).
* Sortie fuel 3.05 kg including reserve, against 1.90 kg in the trade's scaling. Idle fuel from the model is 19 % of max;
  fielded engines are 14-18 %, and Phase 2's A1.4 used 10 %.
* **TOGW 20.0 kg, 5.0 kg under 25 kg.**
* The inherited Phase 2 climb is not flight-path-limited at T/W > 1 (small fuel effect).

**Decision (user, 2026-09-14):** "go ahead with the -15° design". D3R.2 is the baseline, and Phase 4 proceeds on
`ce75000_opr4_t1150_b15_cap`.

**Open for Phase 4** (see the Phase 4 centrifugal entries below for what was done):
1. diffuser design (the diameter driver, worth ~13 points of margin);
2. 3D impeller FE, vibration and LCF (the root sits at Fty at MCS by construction);
3. rotor dynamics at 75k;
4. start and acceleration transients;
5. turbine material data (on its 350 MPa limit);
6. compressor map above 105 % corrected speed.

---

## Phase 4 (centrifugal baseline) — turbomachinery preliminary design and Phase 2 ↔ 4 closure (2026-09-14)

Write-up: `docs/phase4r_centrifugal.md`. Plots: `plots/phase4r_td_check.png`, `phase4r_rotor_critmap.png`,
`phase4r_rotor_final.png`. Scripts: `scripts/phase4_turbomachinery/td_check.py`, `hecc_surge_check.py`,
`cc_blade_modes.py`, `cc_rotor*.py`, `cc_transient.py`, `cc_closure.py`.

### F4R.1 Independent compressor check (NASA turbo-design, HECC-validated)
The code was reviewed before use: no unit errors; no shock loss; no diffuser-stall model; its vaned-diffuser loss cannot
size the diffuser.

On the three OPR-4 / 75k impellers, rebuilt from their meanline geometry without tuning:

| impeller | turbo-design PR / η | TurboFlow PR / η |
|---|---|---|
| 0° | 3.96 / 0.786 | 4.00 / 0.810 |
| -15° | 4.05 / 0.803 | 4.01 / 0.818 |
| -20° | 4.07 / 0.808 | 4.00 / 0.819 |

**The design point is confirmed.** A throat estimated from blade angles (0.63 of the eye area) choked 2 % above design
flow, which confirms that the 10 %-margin throat (0.75 of the eye) is needed.

### F4R.2 The surge surrogate fails on a real vaned-diffuser stage
* **NASA HECC measured:** last stable point at 95.1 % of design flow with PR still rising. Design surge margin 8.4 %.
* **turbo-design on HECC:** the characteristic rises down to 61 % flow, so the surrogate gives >= 73 %.
* **On our -15° impeller:** turbo-design's peak is at 0.94 W_d (SMN 6.5 %), against TurboFlow's 0.80 W_d (28 %).

For vaned diffusers, surge is set by diffuser stall, which neither tool models. **The Phase 3R surge margins are
unvalidated (risk R4R.1, top).** The backsweep trend is confirmed by both tools; its magnitude is not.

### F4R.3 Exducer blade vibration (Morley plate modal, verified -1.5 % against a clamped strip)
Static modes: 9.33 / 15.96 / 28.37 kHz. With 19 diffuser vanes, mode 1 crosses 19/rev at 39 % speed (idle) and mode 2 at
67 %; no engine order 1-6 crosses in 35-105 %. 15-17 vanes would move the static crossings away from idle and from
95-100 %. The vane count is to be chosen together with the diffuser's stall range.

### F4R.4 Rotor dynamics: the bending mode is set by the combustor length
The first shaft-bending mode has 4 % of its strain energy in the bearings, so dampers cannot reach it.
* With the Phase 3 combustor (235 mm bearing span): 38-59 krpm for 16-28 mm shafts, and 74-76 krpm for a 32 mm thin
  tube. All inside the 26-79 krpm range; API fail.
* The bending critical rises steeply as the span shortens. A lighter impeller boss lengthens the span.

### D4R.1 Rotor and combustor configuration
* combustor liner 0.8 × the Phase 3 rule (bearing span 192 mm), with the combustor grown radially to the diffuser
  envelope (OD 184 mm, no diameter cost). Volume-corrected theta -0.42 σ of the 7-engine reference spread;
* AISI 4340 tube shaft 32 × 25.6 mm, 12 mm journals (DN 0.95e6 at MCS);
* damped soft supports, k 1.75e6 N/m, c 876 N s/m.

Criticals:

| critical | AF | position |
|---|---|---|
| 8.3 krpm | 2.64 | 68 % below minimum speed |
| 14.4 krpm | 1.28 | critically damped |
| 105.6 krpm (bending) | - | 34 % above MCS (25.8 % required) |

**API pass.** The bending mode is 34 krpm at rest; gyroscopic stiffening from the overhung impeller lifts its crossing.
Rotor 2.11 kg, Ip 2.13e-3 kg m². Open: combustion performance at L/D_ref 2.2; damper mass.

### F4R.5 Acceleration (SLS, T4 <= 1150 K, SMN >= 5 %)
* 40 % → 95 % in 6.6 s; 45 % → 95 % in 3.5 s. The B300F data sheet quotes 37 → 100 % in 4.6 s.
* Acceleration from idle is limited by surge margin, not T4.
* With a 10 % transient margin the engine cannot accelerate from 40 %.

### D4R.2 Phase 2 ↔ 4 closure
* **Engine:** 6.85 kg calibrated (6.49-7.21), against 6.74 kg: shaft +0.24, casing -0.12, liners -0.06 kg raw. Length
  426 mm (-52 mm), OD 187 mm.
* **Mass budget:** accessories 1.60 + structure 3.82 + gear and chute 1.27 + fuel system 0.40 + systems 2.02 + growth
  1.13 + fuel 2.98 kg.
* **TOGW 20.09 kg, 4.91 kg under 25 kg. Closes.**
* **Checks:** dash margin +54.7 / +28.5 %; transonic minimum excess thrust 116 N (pessimistic); take-off roll 46 m.
* **Landing at 17.7 kg:** 175 m with flaps + chute; 316 m with flaps only. The chute stays required for 300 m.

**Decisions for the user before the design freeze:**
1. how to secure the surge margin: diffuser designed for range, vaneless diffuser, -20° backsweep, bleed or variable
   nozzle, or a rig test;
2. the diffuser vane count, together with (1);
3. whether to accept the shorter combustor pending combustor data.

---

## Phase 5 — design freeze: status snapshot for review (2026-09-14)

User request: compile `docs/design_freeze.md` from the current state (Phase 4R, -15° backsweep, with the rotor fix) as
a snapshot for review. Carry the open risks forward explicitly; do not start Phase 6.

### D5.0 Freeze document compiled; sign-off NOT given
No new analysis was run for the freeze; every number comes from the Phase 3R / 4R data files.

Contents:
* architecture, cycle and components (section 1);
* airframe closure: TOGW 20.09 kg, +54.7 / +28.5 % dash margin, 46 m take-off roll, 175 m landing with chute
  (section 2);
* rotor dynamics: API pass and the fix that got there (section 3);
* open risks (section 4);
* what CAD would commit to (section 5);
* decisions for the reviewer (section 6).

Precisions against the request, as the data show:
* the worst-corner margin +21.8 % dates from Phase 3R (before the Phase 4 engine changes) and was not re-run;
* the grown, shortened combustor has 94 % of the Phase 3R liner volume and volume-corrected loading 0.92 × the
  reference mean: near parity, not exact;
* the idle-range surge margin is 8.4-8.7 % at 35-40 % speed and 13 % at 45 % (TurboFlow surrogate).

**Open risks carried, none resolved:**
1. surge margin (no validated method; tools 28 % vs 6.5 %; the surrogate is wrong by ~9× on HECC; the diffuser redesign
   has not been run);
2. idle-range surge margin and acceleration (the start bleed has not been sized);
3. combustor shortened 20 %, unverified;
4. the 19 diffuser vanes excite exducer mode 1 at idle (39 %);
5. no rig or bench validation;
6. carried items (exducer root at Fty at MCS, turbine on its limit, dampers, DN, diffuser sets OD, worst corner < 25 %,
   and others).

**Phase 6 (CAD) not started**, awaiting the user's review and sign-off.

---

## Phase 6 — CAD / 3D: toolchain step (2026-09-14)

**User instruction:** "continue phase 6", given after the Phase 5 snapshot. It is taken as the go-ahead to enter
Phase 6. The freeze's open decisions (surge margin, diffuser vane count, combustor length) were not answered and remain
open. The brief's first Phase 6 step is to propose the CAD toolchain and confirm it with the user **before any geometry
is generated**, and this entry covers only that step.

### D6.0 Toolchain proposed; install verified; awaiting confirmation (`docs/phase6_toolchain_proposal.md`)
* **Separate `.venv-cad`** (Python 3.12.10, NumPy 2.5.3, `requirements-cad.txt`) with CadQuery 2.8.0 (OCCT 7.9.3),
  gmsh 4.15.2 and pyturbo-aero 1.3.8. The frozen `.venv` and `.venv-np1` are untouched.
* **Verified** (`scripts/phase6_cad/smoke_cad.py`, primitives only), all exact to rounding:
  * box volume and STEP round trip;
  * B-spline surface through cylinder points against the analytic area;
  * spline-section loft against the analytic volume, valid solid;
  * gmsh tetra volume.
* **Findings:**
  * pyturbo `Centrif` outputs point clouds only (no solids, no export), and has a shared class-level `patterns` list;
  * the OCP bindings need enum arguments;
  * the smoke process exits non-zero at teardown after passing.
* **Proposed plan:**
  1. parameter sheet with frozen / provisional tags;
  2. 2D meridional layout;
  3. impeller from pyturbo-aero, checked against the analysis;
  4. the other components as conceptual solids, assembled in STEP;
  5. optional 3D impeller FE (gmsh + scikit-fem, verified first).

  Diffuser, combustor, bearing span / shaft and the bleed provision are modelled parametrically.

No engine geometry has been generated.

**User confirmation (2026-09-14):**
* toolchain: CadQuery + pyturbo-aero + gmsh (as proposed);
* scope: **engine + airframe + 3D impeller FE**;
* open items: **provisional parts modelled parametrically**, with the decisions staying open in
  `docs/design_freeze.md`.

Geometry generation starts with the parameter sheet.

### D6.1 Parameter sheet (`scripts/phase6_cad/make_params.py` -> `data/phase6/engine_params.json`, `airframe_params.json`)
* Every CAD dimension is an entry `{value, unit, status, source}`, with status one of: **frozen** (from the freeze),
  **derived** (computed from frozen values), or **provisional** (a construction rule no analysis fixed).
  **29 of 74** engine parameters are provisional. These are the freeze's open items (diffuser, combustor, bearing
  span / shaft) plus the LE radius and the impeller camber law.
* Consistency checks (`params_consistency.json`):
  * eye velocity C1 = 200.2 m/s, β1 hub / rms / shroud 34.3 / 55.6 / 62.8° (zero incidence);
  * component length 352.5 mm against the calibrated envelope 426 mm (the calibration adds length for items not
    modelled; the CAD keeps the calibrated cylinder as a reserved volume).
* **Airframe inputs updated:** capture area 47.5 → 55.1 cm² (Phase 3R fielded flow) and nozzle A8 49.1 → 70.8 cm²
  (the Phase 4 engine's throat). Both were stale Phase 2 values.
  * Re-running the Phase 2 drag model with them gives CDS 81.89 → 81.66 cm² nominal and 98.64 → 97.70 cm² pessimistic
    (−0.3 % / −1.0 %). Negligible; the closure is not re-run.

### D6.2 Engine CAD (`engine_cad.py` -> `cad/engine/*.step`, `cad/engine_assembly.step`)
* 27 parts, all valid solids.
* Construction:
  * revolved profiles for the casings, liners and rings;
  * log-spiral diffuser vanes (19) and 30 placeholder deswirl vanes;
  * NGV (34) and rotor (28) rows built as planar sections with polygon wires and ruled lofts. Spline sections
    self-intersected at the TE cusp (volume off 19 %). Single-vane volume matches area × height to 0.1 %;
  * Stodola turbine disc (engine_mass law), shaft with journals, bearings, housings, tunnel;
  * impeller imported (D6.3).
* **Envelope rule found:** the diffuser OD sets the engine OD (r4 + 3 mm), so the 90° bend into the deswirl annulus
  must turn **inside r4**. The diffuser back plate stops at the deswirl inner radius.
* **Size:**
  * bounding box 382.5 mm long including the 30 mm inlet lip; components 352.5 mm; calibrated envelope 426 mm;
  * OD 186.6 mm, equal to the envelope.
* **Mass** (`mass_compare.py`, CAD against the RAW bottom-up model, since the ×1.20 calibration covers the items the
  CAD does not draw):
  * total: CAD 5.19 kg against 4.92 kg for the model items that are drawn (+5.4 %). The model's starter, fuel manifold
    and 10 % fasteners (0.78 kg) are not drawn;
  * items: impeller +17 %, shroud / inlet +19 %, outer casing +53 %, diffuser + deswirl −49 %, shaft −26 %, turbine
    items within ±20 %;
  * so the calibrated 6.85 kg is not contradicted, but the item split is.

### D6.3 Impeller CAD (`impeller_cad.py`; pyturbo-aero + CadQuery)
* **Inducer throat, found:** the tool-level design ratio 0.75 × eye was not met by the first CAD camber (0.611 × eye).
  * TurboFlow's `area_throat_ratio` multiplies the eye area. Its choke check is isentropic relative flow through
    A_throat, at the mean eye radius.
  * Reproduced by hand at tool level: 0.70 → 1.086, 0.75 → 1.164 × design flow, the same bracket Phase 3R found.
  * On the larger fielded eye, the Phase 3R requirement (10 % choke margin) needs **0.665 × eye**. The first CAD camber
    gave 1.010 × design flow, i.e. ~1 % margin.
* **Camber law replaced (provisional, analysis-traceable):** θ = θ_rf(x) + θ_bs(r).
  * Radial-fibre inducer, θ_rf′(x) = (ω/C1)(1 − x/L)^n. Zero incidence at every LE radius at once; no centrifugal
    bending of the inducer, as the gate's inducer-root estimate assumed.
  * Plus exducer backsweep, linear in r from 0 at 0.7 r2 to 15°: the plate model's own law.
  * The TE metal angle is 15° on every span.
  * pyturbo's 4-point Bezier with one TE θ for all spans could not deliver this. It hooked from 43° to 15° in the last
    10 % of chord at the shroud. Replaced through the `__build_camber__` hook by a 14-point least-squares Bezier
    (fit ≤ 0.6°).
  * **n = 3**, the smallest exponent meeting the 10 % margin (n 2 / 2.5 / 3 → choke 1.040 / 1.072 / **1.102** × design).
    This means fast inducer unloading: shroud metal angle 62.8° at the LE, 42.8° at 30 % chord. The inducer
    diffusion / loading this implies has not been analysed (no CFD) — new open item.
* **Checks:**
  * CAD metal angles within 1.1° of the law along the chord;
  * TE measured 11.6 / 13.1 / 14.2° hub / mid / shroud over the last grid segment against 13.9 / 14.4 / 14.8° target
    there (the TE closure rounds it);
  * thickness 2.23 mm root and 0.80 mm tip (sized 2.235 / 0.8);
  * throat 0.667 × eye, choke **1.102 × design**.
* **pyturbo / OCCT problems met and fixed** (tools_survey section 9):
  * the SS / PS are Beziers through control points (`camber_follow_density = 60`);
  * `splitterblade` sits at the main blade's θ, so every splitter lay inside a main blade until rotated half a pitch;
  * faceted blades: fan caps gave silently failing booleans, and even with ladder caps the sliver-tet meshes followed;
    now **smooth B-spline blade solids** (grid points on the surface to 1e-5 mm).
* **Sector and wheel:**
  * the FE sector is bounded **through the passages** by radial-line ruled surfaces ψ = ψ_main(x) − 22.5° / +7.5°, so
    no blade is cut. Flat cut planes cut every blade, and the slivers made the FE near-singular;
  * 1 solid; volume closure 3e-5; 12 × hub sector = hub to 2e-8;
  * the wheel is 12 copies of the sector.
* **Mass:** wheel 1.082 kg (hub 0.944, blades 0.138).
  * The CAD hub matches the axisymmetric FE's hub to 0.04 %.
  * The stress model's impeller is 1.132 kg (smeared blades at 1.52 mm mean thickness), so its blade pull on the hub
    is ~36 % heavier than the CAD blades: conservative for the hub.
  * Ip 1.287e-3, Id 8.29e-4 kg m², CG 36.2 mm from the nose.

### D6.4 Airframe integration (`airframe_cad.py` -> `cad/airframe/*.step`, `cad/aircraft_assembly.step`)
* **Built:**
  * fuselage OML with the D2.6 area-rule waist (as the drag model assumes), 1.5 mm skin;
  * pitot intake duct straight to the engine face at x = 1.315 m;
  * biconvex wing / tail panels;
  * jetpipe to the tail nozzle;
  * engine assembly plus the calibrated envelope as a reserved volume. All parts valid.
* **Findings** (not in any earlier model):
  1. **engine-to-skin radial gap 8.7 mm**, at x = 1721 mm where the waist is deepest over the envelope. Positive, but
     thin for structure, mounts and insulation around a hot casing;
  2. **jetpipe** 1.09 m long at M 0.34, 64.1 mm radius:
     * friction ΔPt/Pt ≈ 0.64 % (Haaland), not in the cycle (nozzle Cv 0.98 only). Rough thrust effect −1.7 %
       (estimate, not run through the cycle);
     * the turbine exit swirl (−17.8°, TurboFlow) is not recovered in the model, arguably covered by the fielded
       calibration;
     * at the tail the jetpipe wall is the nozzle lip (−0.5 mm "gap" to the boattail skin at the exit);
  3. **fuel:** the forebody annulus around the duct holds 13.75 L gross against 3.72 L of fuel (27 %). It shares that
     space with avionics, batteries and instrumentation (not laid out);
  4. intake duct: area ratio 1.42 over 1.29 m (0.36° equivalent cone), benign.

### D6.5 3D FE of the impeller (`fe3d_impeller.py`; gmsh + scikit-fem P2 tets + cyclic tie; `data/phase6/fe3d_impeller.json`)
* **Model:**
  * the 30° passage-bounded sector (D6.3); centrifugal load at MCS (105 % of 75 000 rpm);
  * Ti-6Al-4V, E 110 GPa, no thermal load;
  * boss held axially within the 6 mm stub-shaft radius; the rigid rotation about x is held by a weak spring and
    subtracted from the reported displacements.
* **Cyclic symmetry:** a tie. Each slave-face DOF is interpolated from the P2 trace of the master face, because gmsh
  `setPeriodic` needs matching face topology.
* **Verification** (same code path):

  | case | FE | reference | difference |
  |---|---|---|---|
  | (A) rotating disc, centre stress | 451.8 MPa | 452.8 MPa (theory) | −0.2 % |
  | (A) outer-band hoop | 185.6 MPa | 185.7 MPa (theory, same points) | −0.05 % |
  | (B) hub alone, flat cuts, peak von Mises | 307.9 MPa | 311.6 MPa (verified axisymmetric FE) | −1.2 % |
  | (B) average hoop | 160.0 MPa | 159.8 MPa | +0.1 % |
  | (B′) same hub, twisted passage cuts | 308.0 / 160.0 MPa | as (B) | tie points within 2e-9 mm of the master face |

  * Hoop stress within 2 mm of the axis: 249 vs 260 MPa (−4 %, sampling of that small region).
* **Solvers:**
  * pyamg converged on (B) (agrees with SuperLU to 1e-7) but stalled with the interpolated tie;
  * SciPy SuperLU paged at 220 k DOF;
  * MKL PARDISO (pypardiso, added to `.venv-cad`): matches SuperLU to 5e-7 on (B′), residual ~1e-11, 8-14 s.
* **Rejected intermediate runs, recorded so they are not reused:**
  * flat-cut sector: near-singular stiffness (AMG stalled at 3 % residual);
  * faceted blades: 15 % sliver tets, 1e6 MPa spurious peaks.
* **Production results at MCS** (mesh 40 k tets baseline / 61 k tets fine, quality median 0.72 / 0.75):

  | quantity | baseline | fine | reference |
  |---|---|---|---|
  | **exducer root** hot spot (0.4 t / 1.0 t extrapolation, > t_root from the blade ends) | 426 MPa | **413 MPa** | Phase 3R plate model nominal 441 MPa |
  | exducer root × Kt 1.4 | 596 MPa | **578 MPa** | plate 618 MPa; **Fty 622 MPa** |
  | **inducer root** hot spot (same rule) | 360 MPa | **355 MPa** | gate estimate 196 MPa (radial-fibre tension, k 0.6) |
  | inducer root × Kt 1.4 | 505 MPa | 497 MPa | Fty 622 MPa |
  | **hub** > 1 mm inside the surface, 99.9th percentile | 331 MPa | **333 MPa** | axisymmetric with smeared blade pull 313 MPa |
  | hub single-point maximum | 336 MPa | 438 MPa | not converged; the percentile holds |
  | blade-end corner peaks, LE / TE (singular) | 581 / 630 MPa | 669 / 470 MPa | mesh-dependent |
  | blade tip closing toward the casing (inducer LE tip) | 0.074 mm | 0.074 mm | cold clearance 0.25 mm |

* **Findings:**
  1. **The exducer root sizing holds.** The 3D root stress is 3-7 % below the plate model, which included no hub
     compliance or membrane load. With Kt 1.4 it is 93-96 % of Fty at MCS. The freeze's "exducer root at Fty at MCS"
     item is confirmed as essentially on the limit, not relieved.
  2. **The inducer root is ~1.8× the gate estimate** (355 vs 196 MPa). The load is carried in-plane (membrane stress
     nearly flat from 0.4 t to 1.0 t), and the hub's meridional strain is imposed on the blade root; the 1D radial-
     tension estimate has neither. It is still inside Fty after Kt 1.4 (~25 % margin). This is new information, not
     a failure.
  3. **The hub peak is 6 % above the axisymmetric model** (333 vs 313 MPa mechanical). With the gate's +22 MPa thermal
     gradient that is ~355 MPa, still ~75 % yield margin.
  4. **The blade-end corners are singular in this CAD.** The LE root sits on the hub's front edge (no nose ahead of
     the blades) and the TE root on the rim edge, with no fillets anywhere. Peaks of 470-669 MPa there change with the
     mesh. A detailed design needs a hub nose extension and root / end fillets. Kt 1.4 is an assumed fillet factor
     that no fillet in the CAD represents.
  5. **Tip closing** is 0.074 mm mechanical (30 % of the clearance). Thermal growth of the wheel and casing is not
     included.
  6. **Deflection:** meridional 0.17 mm; tangential blade deflection 0.44 mm (no clearance effect).
* **Not done:** thermal load, vibration modes of the 3D blade (Phase 4R used the plate model), fillet geometry,
  contact at the stub shaft.

### D6.6 Figures and tool additions
* `render_cad.py` (VTK off-screen, matplotlib) writes:
  * `plots/phase6_engine_cutaway.png`, `phase6_engine_section.png`;
  * `phase6_impeller.png`, `phase6_impeller_sector.png`, `phase6_impeller_fe.png`;
  * `phase6_aircraft.png`, `phase6_aircraft_cutaway.png`, `phase6_aircraft_section.png`.
  * Off-screen VTK dropped translucent actors, so the aircraft interior is shown as a cutaway.
* `.venv-cad` additions (in `requirements-cad.txt`): pyamg 5.3.0, pypardiso 0.4.7 (MKL 2026.1), each checked against
  SciPy's SuperLU before use.
* **Engine specification PDF** (user request, 2026-09-14): `scripts/phase6_cad/spec_sheet.py` → `docs/boomsonic_engine_spec.pdf`, 5 pages.
  * Every number is read from the data files at run time. The constants η_b and the turbine blade-root allowable are
    parsed from `dash_cycle.py` / `turbine_design.py`.
  * Two quantities were dropped rather than printed with an unsourced input:
    * an equivalence ratio (it needed a hand-typed stoichiometric fuel-air ratio);
    * an intake recovery from a γ = 1.4 freestream total (it disagreed with the cycle's documented duct loss).
  * The open risks are stated on page 1 and in section 9.
  * reportlab 5.0.1 added to `.venv-cad`; its dependencies pillow and charset-normalizer were already present. The layout
    was checked page by page, rendered with pypdfium2 in a throw-away `uv run` environment, not installed.
* Documentation correction: the freeze and Phase 3R docs said the physical exit width b2 is "12.0 mm". The data say
  11.796 mm; the text now reads 11.8.

---

## Axial design (option A) taken to its freeze — Phase 3A-R refresh (2026-09-14)

**User instruction:** "search the project folder and you will see an early design concept that uses 6 axial stages
take that design paremeters where we left off and finished it as you did with centrigual one". The concept is the pure
axial baseline (OPR 5, 6 stages, 80 000 rpm; D4.2), last worked in Phase 4 (operability D4.4, rotor dynamics D4.R2)
before the switch to the centrifugal (D3R.0). **User decision (AskUserQuestion): pause at the axial freeze for review
before any axial CAD** (brief rule 4). The centrifugal design is not changed. The axial is Phase 3A-R / 4A / 5A, tags
`ax*_3r`, data in `data/phase3ax/`, `data/phase4ax/`.

### F3A.1 The Phase 3 / 4 axial numbers are stale in three ways
1. **Fielded efficiency.** A3.4 debited the axial tool efficiency by 0.70 / 0.794. The 0.794 is the Phase 3 centrifugal
   tool efficiency, computed with TurboFlow's defective slip (F3R.1).
2. **Compressor scaling.** The √W scaling of the tool-level geometry (A3.6) cannot match both the fielded flow (area
   ~ r²) and the fielded work (~ U²) at fixed speed; F3R.3 found the same flaw for the impeller.
3. **Turbine.** The √W-scaled turbine ran past its 350 MPa blade-root limit (F3R.3 applies to every Phase 3 case).

In addition, the mass / length calibrations were re-anchored in Phase 3R (×1.20 / ×1.21).

### A3A.1 Fielded axial efficiency re-referenced
* η_c,fielded = η_c,tool × 0.70 / η_ref, with η_ref = the Phase 3R centrifugal tool efficiency 0.8175
  (`cct_ce75000_opr4_t1150_b15_cap`), so K_F = 0.856 (was 0.882).
* The axial tool efficiency stays 0.8285 (TurboDesigner + Howell, not touched by the slip defect), so fielded
  **0.709** (was 0.730).
* Still an assumption (A3.4). Phase 3 showed the architecture conclusion does not depend on it.

### D3A.1 Method (`scripts/phase3_cycle/ax_trade.py`)
1. **Fielded compressor re-designed AT the fielded cycle.** TurboDesigner at the fielded W / Tt2 / Pt2 / PR 5, with
   the fielded efficiency setting the work. The Howell loss model is evaluated once; it reports the tool-level
   efficiency of that blading. Phase 3 limits apply: DF ≤ 0.5, de Haller ≥ 0.72, rotor-1 tip M_rel ≤ 1.35, last blade
   ≥ 10 mm.
   * Grid: 70-90 krpm × 5-8 stages × hub/tip 0.40-0.55 × Cx 170-200 m/s. 98 of 240 designs are feasible.
2. **Fielded turbine re-designed by TurboFlow** at the fielded cycle (350 MPa, envelope cap).
3. **Engine and airframe:** θ-scaled combustor, engine_mass, 3R calibration, Phase 2 airframe drag.
4. **Worst corner:** η_c × 0.66/0.70, combustor +1σ, pessimistic drag.

### F3A.2 Results (fielded; best blading at each speed; `data/phase3ax_trade.csv`)

| rpm / stages | tool η of blading | rotor-1 M_rel | turbine tip (on the limit) | L | dry mass cal. | margin nom / pess | worst | TOGW |
|---|---|---|---|---|---|---|---|---|
| 70k / 8 | 0.832 | 1.13 | 65.5 mm | 714 mm | 6.41 kg | +104 / +88 % | +71 % | 18.03 kg |
| 75k / 7 | 0.832 | 1.20 | 61.1 mm | 651 mm | 5.64 kg | +104 / +88 % | +71 % | 17.27 kg |
| **80k / 6** | 0.832 | 1.27 | 57.3 mm | **599 mm** | **5.02 kg** | **+104 / +89 %** | **+71 %** | **16.65 kg** |
| 85k / 6 | 0.827 | 1.32 | 53.9 mm | 593 mm | 4.83 kg | +104 / +89 % | +71 % | 16.46 kg |

* Fielded airflow 1.360 kg/s (was 1.314), TSFC 0.159 kg/(N h).
* Every case is combustor-set at **OD 142.5 mm**, so drag and margins are equal.
* TurboFlow flags the 75k turbine `success=False` at a point on its stress limit to 1e-9 mm (known quirk, tools_survey
  section 8).

### D3A.2 Refreshed baseline: 80 000 rpm, 6 stages, hub/tip 0.40, Cx 200 m/s
* **Why:**
  * margins are equal across the grid, so length and mass decide;
  * 80k is 51 mm shorter and 0.62 kg lighter than 75k;
  * 85k saves only 0.19 kg (1 % of TOGW, inside the ±5 % mass calibration band), but takes rotor-1 to M_rel 1.32 of
    the 1.35 limit, raises bearing DN by 6 %, and has had no rotor-dynamics check.
* Same speed and stage count as the Phase 3/4 baseline.
* **Against Phase 3:** mass 5.74 → 5.02 kg (the turbine re-design), length 611 → 599 mm, OD 142 → 142.5 mm, dash margin
  unchanged.

### F3A.3 Validation attempt for R4.1 (published small-axial test data)
* **NASA-CR-134827** (AiResearch 1976, scaled single-stage transonic axial, 70-110 % speed): tip clearance 1.0 → 2.2 % of
  blade height, both with casing treatment, cost 5.7 − 3.5 = 2.2 efficiency points, ≈ 1.8 points per 1 %. The model
  uses 2.0 points per 1 %, which is consistent.
  * The same test: stall margin 12.8 → 8.7 %. **The stacking model has no clearance effect on stall**; noted for
    operability.
* **NACA TR-758** (8-stage axial, 1943): has speed lines at 5 000-14 000 rpm and stage-by-stage pressures. The text layer
  gives geometry and summary numbers, but the characteristics are scanned figures. A multistage part-speed benchmark of
  the stacking model is possible, but needs the geometry rebuilt and the figures digitised; the machine is large,
  subsonic and lightly loaded. **Not run**; offered as an option at the freeze.
* NASA-TM-106999 (small 2-stage rig, 1995): inlet calibration only, no maps.
* **R4.1 stays open.** Only the clearance sensitivity is supported by data.

### F4A.1 Rotor stress screening (`ax_rotor_stress.py`, 80k blading, MCS 105 %, Ti-6Al-4V Fty 620 / Ftu 681 MPa)
* **Verification:** the rotating-beam FE reproduces the static cantilever (3.5160 / 22.0345) exactly and Wright et al.
  (1982) at speed parameters 1 and 2 (3.6816 / 4.1373) to 0.001 %.
* **Blade roots:** centrifugal + gas bending on a biconvex section, × Kt 1.4.
  * The mass model's constant-section stage-1 blade fails: 677 MPa. U_tip at MCS is 461 m/s.
  * **A 10 % thickness taper** (root 1.65 / tip 1.35 mm, same mass) gives 598 MPa (96 % of Fty). Stage 2 is at 597 MPa
    (96 %); stages 3-6 are at 523-550 MPa.
  * The taper is provisional geometry.
* **Discs:** the mass model's 450 MPa constant-stress discs give a burst ratio of 1.08 at MCS, failing the ≥ 1.20
  criterion used for the impeller. Re-sized to 365 MPa at design speed (402 MPa at MCS), which gives 1.20. Mass
  **+0.009 kg**: the 4 mm minimum rim governs these small discs.
* **Blade vibration** (1F / 2F with centrifugal stiffening, taper included): low-engine-order crossings in the likely
  operating range:
  * stage 1: 1F × 2E at 61 %;
  * stage 2: 1F × 2E at 79 %;
  * stage 4: 1F × 3E at 60 %;
  * stage 5: 1F × 3E at 76 %;
  * **stage 6: 1F × 3E at 95 %**, near maximum speed.

  Vane-passing crossings are only with 2F, at 40-43 %. Carried as an open risk; no retuning done.

### F4A.2 Three model problems found running the operability chain on the refreshed design (fixed; Phase 4 results unchanged)
1. **Wrong triangles for a blading sized at a set efficiency.**
   * `axial_offdesign.Compressor` rebuilt the TurboDesigner triangles at the loss-model efficiency (0.832). The 3A-R
     blading was sized at 0.709.
   * Fix: rebuild at `eta_sizing` when present. Phase 3 designs lack the key; the Phase 3 regression is unchanged
     (PR 5.031, η 0.831).
2. **Tool-level losses on a fielded-work blading.**
   * The stacking design point over-delivered PR, which put the design in the wrong place on its own map.
   * Scaling the WHOLE row loss to the fielded efficiency (stage η −0.103) instead doubled the incidence parabola:
     every flow choked below 80 % speed (row losses so large that the exit could not pass any flow). That is a model
     artefact.
   * **Adopted (`axial_offdesign.fielded`):** stage losses calibrated so the design point gives the fielded 0.709 and
     PR 5.09 at the design flow. Off design, only the tool-level (Howell) part follows the incidence parabola; the
     fielded debit (clearance / Re / finish-type) is a **constant extra loss** (ΔY 0.054-0.058 per row).
   * Howell stall is unchanged (deflection-based).
   * Result: lines at all speeds; design SMN to the peak line ~14 %, as in Phase 4. Rotor 1 is past Howell's stalling
     deflection along the whole line below 85-90 % speed, as Phase 4 found.
3. **pyCycle off-design start.**
   * `cycle_model.set_design` seeds every off-design point with W 2.0 lbm/s, FAR 0.018, turbine PR 2.0. At η_c 0.730
     (Phase 4) that converges; at 0.709 (W 3.0 lbm/s, turbine PR 2.64) Newton diverged to NaN at every point. The
     Phase 4 maps gave the same failure at 0.709 and converged at 0.730, so the maps are not the cause.
   * **Fix:** `cycle_model.seed_od_from_design` copies every implicit state from the design point (map balances from
     the design map location) and re-solves. The off-design point is then marched from the design flight condition.
   * Verified: the off-design point reproduces the design (500 N, 1150 K); SLS 100 % gives 686 N at T4 1169 K.
   * Not used by any Phase 3 / 4 script.

### D4A.1 Operability: combined variable geometry (option A) sized (`ax_operability.py`, `ax_operability_summary.py`)
* **Criteria (Phase 4):** a steady point is acceptable if converged, T4 ≤ 1150 K, no row beyond its Howell stalling
  deflection, and SM to the peak line ≥ 10 % (the transient half of ~20 %). Idle = the lowest speed from which every
  point up to the T4-limited maximum-throttle speed is acceptable.
* **Scheduling corrections during the search** (first batches wasted, recorded):
  * **Bleed and nozzle opening at 95 % speed.** The Phase 4 setting (90 %) acts below the first fixed-geometry failure
    (92.5 %, SM 9.2 %).
  * **VIGV as a scheduled closure** (design swirl at ≥ 95 %, closing linearly by Δ at 60 %). The Phase 4
    stall-index-driven schedule never closed the IGV here, because the binding limit is the surge-surrogate margin.
* **Results at SLS** (max throttle 97.5-98.7 % in every configuration, T4-limited):

  | configuration | idle | idle thrust | idle fuel | limit below idle |
  |---|---|---|---|---|
  | fixed geometry | 95 % | 573 N | 20.3 g/s | SM 9.2 % |
  | 10 % bleed | 87.5 % | 396 N | 16.7 g/s | SM 9.4 % |
  | nozzle ×1.6 | 92.5 % | 500 N | 18.2 g/s | SM 8.4 % |
  | VIGV 15-30° + 10 % bleed | 85 % | 338-348 N | 14.9-15.3 g/s | SM, stator 1 |
  | VIGV 15-30° + 10 % bleed + nozzle ×1.6 (at 40 %) | 80 % | 222-231 N | 11.8-12.2 g/s | SM 7.7-8.9 % |
  | **VIGV 15° + 10 % bleed + nozzle ×2.0, fully open at 80 %** | **77.5 %** | **114 N** | **10.0 g/s** | **stator-1 stall at 75 %** |
  | 15-20 % bleed (any) | none below 97.5 % | | | T4 1159-1207 K at 95 % |

  * At SM ≥ 5 % the best idle is still 77.5 %, with stator-1 stall binding. The VIGV unloads rotor 1 and loads stator 1,
    as Phase 4 found.
  * Nozzle ×2.5 gives 77.5 % / 91 N.
* **Adopted:**
  * VIGV 15° closure (stage-1 swirl 22.4° → 28.7° at idle);
  * 10 % overboard bleed after stage 3, open ≤ 95 % speed;
  * variable nozzle to 2.0 × A8 by 80 % speed.
* **Idle 77.5 % speed:** SM 11.9 %, T4 878 K, 114 N, idle fuel 41 % of the 100 % SLS fuel flow (the centrifugal: ~19 %).
* **Dash line** (VIGV scheduled, bleed closed, nozzle design): acceptable from 100 % down to 87.5 % speed (184 N);
  rotor 1 stalls below.
  * Dash cruise needs ~245 N (throttle 49 %): 90 % speed, SM 12 %, no bleed.
  * The engine cannot be throttled below ~184 N at M 1.02 without the bleed (not analysed).

### F4A.3 Idle thrust makes a powered idle approach impossible
* Approach drag (Phase 2 airframe model, 14-16 kg, M 0.12-0.20): **15-21 N** (L/D 7.5-9).
* Idle thrust: 114 N static (≈ 100 N net in flight after ram drag), **5-6 × the approach drag**; 231 N with the nozzle at
  1.16.
* A conventional descent / approach at idle is not possible. The engine must be **shut down at the top of descent**
  (glide from 5 km at L/D 7-9, dead-stick landing with flaps and the 0.6 m chute), or a thrust spoiler / reverser /
  large airbrake added (not assessed).

### D4A.2 Rotor (`ax_rotor.py`, verified ROSS model; idle 80 % for the assessment)
* The mass-sized Phase 3 rotor passes at 2 of 6 support settings: its bending mode (57-61 krpm, 71-77 % speed) now lies
  below idle. Not robust.
* The stiffened rotor passes at all 24 settings.
* **Adopted:** layout A, 2 mm Ti drum, 24 / 12 mm AISI 4340 shaft, **12 mm journals (DN 1.01e6 at MCS: R4.R2 largely
  resolved)**, supports k 1.75e6 N/m / c 876 N s/m.
  * Criticals 2.8 / 12.4 (AF 2.0) / 19.6 (1.3) / 39.9 (1.2) krpm, all below idle and critically damped; 122.3 krpm
    (46 % above MCS).
  * Rotor 1.60 kg (mass-sized 1.10), Ip 8e-4 kg m².

### D4A.3 Phase 2 ↔ 4 closure (`ax_mission.py`, `ax_closure.py`)
* **Deck:** stacking map with the VIGV schedule, fielded TurboFlow turbine map.
  * SLS max 659 N at 98.7 % (T4-limited, SM 10.5 %).
  * Dash 500 N at 100 %, SM 13.9 %.
* **Engine:** 5.02 → **6.86 kg** calibrated (6.50-7.22), L 599 mm, OD 142.5 mm (combustor-set; liner 157 mm,
  U_ref 29.8 m/s).
  * Raw changes: shaft 24 / 12 (0.95 kg raw), drum 2 mm (0.26), discs +0.009.
  * Variable geometry 0.64 kg raw (geometric estimates + 3 × 75 g servos; not sourced from a fielded design):
    VIGV 0.165, bleed 0.122, nozzle 0.354.
* **Closure with the mission model's powered idle descent:** fuel **5.46 kg**, **TOGW 22.12 kg**, margin 2.88 kg.
  * Dash margin +103 / +88 %; time to dash 29.1 s; ground roll 54 m; landing 177 m (flaps + chute).
  * About 4.5 kg of the fuel is idle-related: the 235 s descent from 5 km, the pattern, and the 120 s reserve, all at
    41 % of max fuel flow. That descent is inconsistent with F4A.3.
* **Engine-off descent variant** (engine shut down at the top of descent, reserve 120 s at idle fuel flow kept): fuel
  **1.88 kg, TOGW 18.54 kg, margin 6.46 kg**, dash margins unchanged.
  * Not a like-for-like comparison with the centrifugal (20.09 kg, flown with a powered descent at its ~19 % idle).

### D4A.4 Acceleration (`ax_transient.py`, `data/phase4ax/accel_<tag>.csv|json`)
* **Method** as `cc_transient.py`:
  * pyCycle NT4 (speed and T4 imposed);
  * VIGV / bleed / nozzle on their schedules;
  * usable excess power under T4 ≤ 1150 K, no Howell stall, SM ≥ 5 % or 10 % to the peak line;
  * dN/dt = P / (I_p ω) with I_p 8.07e-4 kg m² (D4A.2 rotor).
* **Solver fixes needed:**
  * first run: T4 stepped 1150 → 700 K in one jump diverged, and the diverged state poisoned every later point, so no
    speed had a converged point;
  * second run: stepping T4 down from 1150 K in 15 K steps reproduced 80-98.5 %, but still found nothing at 77.5 %;
  * final: speed is marched along the steady line with T4 imposed at its steady value, then T4 is swept up from
    there, and `solve()` restores the last converged output vector after any failure.
  * The excess powers of the second and final runs agree at 80-98.5 % (e.g. 29.28 kW at 90 %).
* **Check:** imposing the steady-line T4 of the N-mode operability run gives a net shaft power of 0.0 kW at every speed
  from 77.5 to 97.5 %.
* **Result (SLS), idle 77.5 % → 98.5 %:** **1.73 s** at SM ≥ 5 %, **2.25 s** at SM ≥ 10 %. Of that, 95 → 98.5 % takes
  1.09 s, because the steady T4 is within 4-25 K of the limit there. At idle with a 10 % reserve only 2.2 kW is usable.
* **Why it is fast:** light rotor (38 % of the centrifugal's Ip) and a short speed span (10.5 kJ of rotor kinetic
  energy). The centrifugal takes 6.6 s from 40 % to 95 %.
* **Not modelled:** actuator rates (the VG is assumed to follow its schedule instantly), the transient when the bleed
  closes at 95 %, fuel-control and heat-soak dynamics, deceleration. The margins are measured against the unvalidated
  surrogate (R4.1).

### D5A.1 Axial freeze snapshot issued; paused for the user's review
* **Documents:**
  * `docs/phase4a_axial.md`: Phase 3A-R / 4A report, with plots `plots/phase4a_operability.png` and
    `plots/phase4a_blade_campbell.png` (`ax_plots.py`);
  * `docs/design_freeze_axial.md`: architecture, closure for both descent concepts, rotor dynamics, open risks,
    Phase 6 starting point, reviewer decisions, and a centrifugal vs axial comparison.
* **Open risks stated, none resolved:**
  * R4.1, the unvalidated axial model (top risk);
  * idle 77.5 %, which forces an engine-off descent (relight and go-around not assessed);
  * start not analysed (below 70 % the model has no steady match);
  * unsourced variable-geometry hardware;
  * dash throttling below 184 N needs the bleed;
  * blade roots at 96 % of Fty;
  * five low-order blade resonances;
  * transient quasi-steady only;
  * no hardware validation;
  * others as carried.
* **Decisions put to the user:**
  1. centrifugal or axial;
  2. the descent concept (engine-off, or a spoiler / reverser assessment);
  3. the NACA TR-758 benchmark;
  4. a like-for-like centrifugal closure with an engine-off descent;
  5. axial Phase 6.
* **No axial CAD started. The centrifugal baseline and its Phase 6 work are unchanged.**

---

## Phase 6A (AXIAL OPTION, EXPLORATORY) — packaging and mass CAD (2026-09-15)

> **Scope banner.** This section is a **separate, exploratory branch on the axial option**
> (`ax80000_opr5_t1150_n6_cap_3r`). It is **not** part of the centrifugal Phase 6 work above, it is **not a build
> release**, and it is **not an architecture decision**: the centrifugal remains the baseline, its Phase 6 status is
> unchanged and still held, and freeze decisions 1-5 of `docs/design_freeze_axial.md` remain open. Phase 6A was run on
> the user's instruction to resolve as much of axial **open risk 4.4 (unsourced variable-geometry hardware)** as
> geometry and mass can, and to test whether the shaft, bearings, bleed ducting and VIGV actuation ring fit inside the
> 142.45 mm engine OD. Scope was packaging and mass only: no manufacturing drawings, no tolerancing, no blade aero
> surfaces. **R4.1 and the other axial open risks are untouched.**
> Report: `docs/phase6a_axial_cad.md`.

### D6A.1 Toolchain and scope confirmed by the user
* **CadQuery 2.8 / OCCT 7.9 in `.venv-cad`** (user choice over FreeCAD): already the Phase 6 stack, `cadlib.py`
  helpers reused, volume-checked booleans, direct mass properties, STEP export, no fourth environment.
* User also confirmed: actuators to be selected from **real published datasheets** (web-sourced, cited), and the
  **bleed discharge path modelled only to the engine OD** (no airframe routing).
* Geometry source rule set by the user and followed: **per-stage numbers, no scaling, no even spacing.** Stages come
  one by one from `data/phase3ax/axt_<tag>.json` `levels.fielded.comp.stages`; the axial stack-up uses the
  compressor's own rule (`axial_design.py:41`, `row_gap_to_chord = stage_gap_to_chord = 0.25`); disc, bearing and
  turbine stations come from `rotor_model.geometry()`, so CAD and rotor model share one layout. Stage pitch runs
  51.6 / 40.7 / 33.1 / 27.6 / 23.4 mm: even spacing would have misplaced the rear stages by ~26 mm.
* New files: `scripts/phase6a_axial_cad/{make_params_axial,ax_flowpath_check,ax_engine_cad,ax_vg_cad,ax_clash,ax_mass_compare}.py`,
  `data/phase6a/*`, `cad/axial/*`. **Nothing under `data/phase3ax`, `data/phase4ax`, `data/phase6` or `cad/engine` was
  modified.**

### A6A.1 Variable-geometry actuation loads (first-order, stated relations)
* **VIGV**: cascade lift `CL = 2 (s/c) cos a_m tan a2` at the 22.4 deg design swirl, q 19.4 kPa at the compressor
  face -> 8.6 N per vane, hinge moment 24.6 N mm per vane (centre of pressure 0.15 c aft of a 0.30 c spindle, bushing
  friction mu 0.2), **unison-ring force 57 N**, stroke 1.57 mm.
* **Bleed**: choked port area 3.34 cm2 (10 % of 1.360 kg/s at 257 kPa / 433 K, Cd 0.8), seal force 68 N,
  **band torque 1.02 N m** (mu 0.3 at r 50.0 mm).
* **Nozzle**: mean flap inner static 82 kPa against 54 kPa ambient -> 56 N per flap, and the linkage-independent
  invariants **27.0 N m total hinge moment over 14.1 deg = 6.7 J of work**. The modelled linkage turns that into
  729 N at the sync ring over 33.9 mm.
* These are conceptual relations, not a validated actuation analysis.

### D6A.2 Actuators selected from datasheets; the nozzle has no compliant part (F6A.1)
`data/phase6a/actuators.json`, transcribed and cited.
* **VIGV: Volz DA 22-12-2615**, 105 g, rated 0.80 N m. Demand 0.285 N m on a 5 mm arm, 18.3 deg travel:
  **36 % utilised, compliant**; ~16 deg C at the compressor face, inside the -30..+70 C rating.
* **Bleed: Volz DA 22-12-2615**, 105 g. Demand 0.51 N m through a 2:1 crank: torque compliant (64 %), but the
  stage-3 manifold is at **433 K (160 C) against a +70 C rating** - **not compliant on temperature**; a thermal
  standoff is required and was not designed.
* **Variable nozzle: NOT COMPLIANT.** Holding 27.0 N m on the DA 22-12-4112's 1.20 N m rated torque needs a
  **22.5:1 reduction**, giving 317 deg of servo travel (reachable only with the optional 330 deg version) and
  requiring a screwjack/gear stage that **is not in the freeze's 0.279 kg estimate**. On peak torque (3.00 N m) a
  9:1 bellcrank holds it with zero margin. It also sits beside a **937 K** jet against a +70 C rating. The alternative
  (Actuonix P16-50-256, 95 g, self-locking) is worse: 300 N lift / 500 N static against 729 N, and -10..+50 C.
* Sources: Volz DA 22 Technical Specification Rev D (02/2016); Actuonix P16 datasheet Rev B (2016).

### F6A.2 The actuation hardware does not fit inside the 142.45 mm OD (R6A.1)
Boolean-confirmed, `data/phase6a/clash_report.json`. The compressor casing is 110.26 mm OD and the engine OD is
142.45 mm, so the variable geometry has a **16.10 mm radial annulus** (free: `engine_mass` puts sheet metal only over
the hot section). **The smallest dimension of a Volz DA 22 case is 22.0 mm.**

| part | r_max | over the OD | volume outside |
|---|---|---|---|
| nozzle actuator | 127.10 mm | **+55.87 mm** | 81 531 mm3 |
| nozzle reduction stage | 104.91 mm | +33.68 mm | 30 000 mm3 |
| nozzle pushrods | 93.36 mm | +22.14 mm | 1 402 mm3 |
| VIGV actuator | 82.48 mm | **+11.25 mm** | 21 850 mm3 |
| nozzle sync ring | 78.83 mm | +7.61 mm | 7 825 mm3 |
| VIGV cranks | 78.38 mm | +7.15 mm | 601 mm3 |
| bleed actuator | 76.56 mm | **+5.33 mm** | 4 591 mm3 |
| VIGV spindles | 72.38 mm | +1.15 mm | 114 mm3 |

The sync ring is outside before any actuator is added: `ax_closure` sizes it at r8_max + 10 mm = 76.83 mm.
**What does fit:** shaft (1.00 mm to the tunnel), tunnel (7.79 mm to the inner liner), **front bearing 28 mm OD inside
the 20.30 mm inlet hub with 6.30 mm clear** (housing 3.30 mm), the whole bleed manifold / valve / full-area collector
duct (reaching exactly the OD line), the VIGV unison ring (9.25 mm clear of the casing), and the flaps at both stops
(0.07 mm inside the OD at fully open). Fix options (local fairing, which changes the airframe cross-section and hence
the wave drag the dash margin rests on, or remote mounting with long pushrods) are **not assessed**.

### F6A.3 The engine is at least 42.5 mm longer once the mechanisms are packaged (R6A.2)
The VIGV row (chord 17.11 mm + the 0.25-chord gap) does not fit in the 15 mm front allowance: it starts **6.38 mm
ahead** of the compressor front face, its actuator 24.75 mm ahead. The nozzle flaps end 28.1 mm **aft** of the raw
length, the actuator and heat shield 36.1 mm aft. Packaged raw length >= **537.6 mm against the frozen 495.1 mm
(+8.6 %)**; the frozen 598.7 mm calibrated length has no allowance at either end.

### F6A.4 The rotordynamic drum geometry is not buildable as modelled (R6A.4)
D4A.2 used a **2 mm Ti drum at a constant r 26.23 mm** (`ax_closure`'s mean of the rotor hub radii). The hub line
rises 20.30 -> 30.19 mm, so the drum (outer radius 27.23 mm) stands **6.93 / 5.79 / 3.50 / 2.73 / 1.11 / 0.56 mm into
the flow path** at the stage-1 rotor through the stage-3 stator, intersecting those stator vanes and inner bands and
swallowing part of the stage-1/2 rotor blade roots. A buildable drum must follow the hub line, which changes its
bending stiffness. **This does not say the API 684 pass is wrong and it is not re-opened here**: the 122.3 krpm
bending critical (46 % above MCS) should be re-run on a hub-following drum before it is relied on.

### F6A.5 The drawn hot end has its minimum area at the turbine exit, not at the nozzle (R6A.5)
`ax_flowpath_check.py`, area/choking capacity at every drawn station.
* **Method verified first:** the choking relation reproduces pyCycle's own A8 sizing to **-0.6 %**.
* Compressor rows: +17.5 % to +56.2 % capacity margin, comfortable everywhere.
* **Turbine exit annulus 66.02 cm2 vs nozzle A8 70.16 cm2 (A8/A = 1.063)**: at the fielded Pt5 151.4 kPa the annulus
  chokes at **1.292 kg/s against the 1.381 kg/s required (-6.5 %)**.
* **Traced cause:** `arch_trade.turb_pout` assumes an **exit Mach of 0.45** to convert the cycle's Pt5 into the static
  pressure handed to TurboFlow. TurboFlow met that static pressure but left the flow at **408 m/s, -19.5 deg swirl,
  M ~ 0.71**, so its own exit total pressure is **184.0 kPa**, not 151.4 kPa. The annulus is sized for the tool-level
  machine (eta_tt 0.917) while the cycle runs the fielded one (eta_t 0.75). The same tool-vs-fielded mismatch as
  F3R.3 and F4A.2, this time as an area.
* **Consequence:** at high speed the controlling area is upstream of the flaps, so the variable nozzle has less
  authority over the running line than `ax_operability` assumed. How much less is **not assessed**.
* **Not fixed and not re-run.** Reported only.

### F6A.6 CAD mass: the core model holds, the variable geometry is 1.76 x its allowance (R6A.3, R6A.6)
Compared against the **raw** bottom-up items (the x1.2025 calibration covers what the CAD does not draw).
* **Core:** blades -3.0 %, discs -3.1 %, stators -3.4 %, liners -0.4 %, hot casing -0.4 %, turbine disc and NGV rings
  exact. Core CAD 4.154 kg vs 4.289 kg of model items, **-3.1 %**.
* **Two core discrepancies, opposite in sign:** the shaft is **+106 g** (the model's `L_shaft = 0.72 x L_total` gives
  356 mm; the layout needs 434 mm), and the tunnel + bearing housings are **-201 g** (the model's flat +0.12 kg
  housing allowance is the more realistic of the two; the CAD housings are thin placeholders). Bearings +13 g (the CAD
  draws solid rings).
* **`engine_mass` double count:** `ngv_rings` and `turbine_shroud` occupy the same space (8 441 mm3 common volume),
  about 67 g of IN-713LC counted twice.
* **Variable geometry (the point of Phase 6A):**

| system | freeze allowance | CAD | delta | ratio |
|---|---|---|---|---|
| VIGV | 165 g | 232 g | +66 g | 1.40 |
| bleed | 122 g | 200 g | +79 g | 1.65 |
| variable nozzle | 354 g | 695 g | **+342 g** | 1.97 |
| **total** | **640 g** | **1127 g** | **+487 g** | **1.76** |

Of the +487 g: **+248 g is hardware the freeze's estimate did not contain at all** (nozzle heat shield 165 g, the
22.5:1 reduction stage 83 g), +117 g is real actuators against 3 x 75 g, +52 g brackets, +18 g bleed duct. The heat
shield is drawn as a full ring, so the nozzle figure is the softest of the three; the actuator masses are datasheet
values and are firm.
* **For scale only, not carried through and no re-closure run:** calibrated dry mass would go 6.863 -> 7.449 kg
  (+586 g), TOGW 22.12 -> 22.71 kg (margin 2.29 kg) in the powered-descent case and 18.54 -> 19.13 kg (margin
  5.87 kg) in the engine-off case. Both stay under 25 kg.
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

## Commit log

2026-09-13 Phase 1: operating point, thrust lapse at Mach 1, mission profile selection
    - pyCycle placeholder turbojet with RPM- and T4-limited max-throttle modes;
    continuation sweep over Mach 0-1 x 0-11 km (data/phase1_thrust_available*.csv)
    - Finding: 500 N SLS engine gives ~310-325 N at Mach 1 below 5 km (RPM limit,
    ram temperature rise); drag-area budget Fn/q grows with altitude
    - D1.1: 500 N defined at the Mach 1 dash point (cycle design point), SLS derived
    - D1.2: mission = Mach 1 dash at 5 km ISA, 3 km fallback; point-mass energy
    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
    [phase1_design_point_options.csv, phase1_mission_candidates.csv, phase1_mission_candidates_dash5km.csv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]
2026-09-13 Phase 2: constraint sizing, transonic drag build-up, mass budget
    - Parametric airframe + drag build-up: Raymer friction/form, MIL-HDBK-762 base
    drag, whole-aircraft area-rule wave drag with verified slender-body integral;
    AeroSandbox helper models verified (one mis-documented function found)
    - Engine envelope from 26-engine sourced database: 6.83 kg, 188 mm, 453 mm at
    665 N SLS; engine diameter identified as first-order drag driver
    - ADRpy constraint diagram with S-dependent CD0 and pyCycle thrust lapse;
    ADRpy quarter-chord sweep bug found and worked around; landing constraint added
    - Mission re-run with drag polar: M1.02 at 5 km reached in 26 s, dash throttle
    0.67 nominal / 0.81 p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
    [microturbojet_database.csv, phase2_baseline_breakdown.csv, phase2_constraints.csv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]
2026-09-13 Phase 3: dash cycle, centrifugal vs axial architecture trade, thrust margin
    - pyCycle dash design point (M1.02/5 km, 500 N) with intake duct loss inside
    the cycle; Cantera cross-check of combustor-exit state (0.3 % on T4)
    - Vendor calibration: published TSFC implies eta_c ~0.70 / eta_t ~0.75;
    results carried at tool-predicted and fielded technology levels
    - Centrifugal stage (TurboFlow), axial compressor (TurboDesigner geometry +
    verified Howell loss model, since no approved tool predicts axial losses),
    stress- and speed-constrained turbine (TurboFlow optimiser fixes added)
    - Lefebvre theta-scaled combustor: combustor sets diameter; OPR shrinks it
    - Bottom-up engine mass from geometr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
    [phase3_arch_trade_opr4_t1150.csv, phase3_arch_trade_opr5_t1150.csv, phase3_arch_trade_opr5_t1150_cap.csv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]
2026-09-13 Phase 3b: axial-centrifugal option (1-2 axial stages + centrifugal)
    - Screening of axial/centrifugal pressure-ratio split vs spool speed:
    front axial stage caps the shaft at ~70 000 rpm (tip M_rel 1.35)
    - Impeller stress closed: fielded Ti stress factor 1.06-1.58 vs 0.86
    for the pure centrifugal
    - Full-chain runs (TurboDesigner+Howell axial stages, TurboFlow impeller
    and turbine, theta combustor, calibrated mass, Phase 2 drag) for
    1-stage OPR 4/4.5 and 2-stage OPR 4/5, plus robustness corners
    - Verdict: not shorter than the 5-stage axial, heaviest option;
    best variant (2 axial, OPR 4) +75/+51 % margin; relocates the risk
    - Recommendation unchanged; AC 2ax OPR 4 becomes the second c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
    [phase3_arch_trade_opr4.5_t1150_cap_ac1.csv, phase3_arch_trade_opr4_t1150_cap_ac1.csv, phase3_arch_trade_opr4_t1150_cap_ac2.csv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]
2026-09-13 Phase 4 entry gate: impeller stress check of the pure centrifugal at 537 m/s
    Axisymmetric FE (scikit-fem, verified vs Timoshenko & Goodier) of the hub/disc with thermal
    gradient, Robinson burst criterion (14 CFR 33.27 120 % speed), and Morley-plate FE of the
    backswept exducer blade root. Ti-6Al-4V minimum-basis properties at ~250 C.
    Result: disc passes (boreless 304-326 MPa, burst ratio 1.9; bored hub only +3.5 % with thermal),
    but the 30 deg backswept exducer blade root fails (656 MPa at 3.5 mm root vs Fty 620 MPa; needs
    >= 5 mm root, 32 % blockage). Centrifugal not qualified as designed; Phase 4 proceeds on the
    pure axial OPR 5.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
2026-09-13 Phase 4: fix Phase 3 axial blockage error; axial operability and rotor dynamics
    Phase 3 correction: axial_design passed TurboDesigner blockage 0.98/0.96, but TurboDesigner
    uses physical_area = flow_area*(1+blockage), so every axial annulus was ~2x too large. With
    0.02/0.04 the axial trade was re-run: the committed axial becomes 6 stages / 80 000 rpm,
    142 mm (combustor-set) / 611 mm / 5.74 kg, margin +104/+89 % (was 5 st / 65k, 151 mm /
    663 mm / 7.28 kg, +98/+77 %). Recommendation unchanged. The Phase 3b "front stage caps the
    shaft at ~70k" result was an artifact; the corrected axial-centrifugal at 90k is 6.1 kg,
    564-610 mm, +75/+50 %. Erratum in docs/phase3_engine.md section 14.
    Operability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
    [phase3_arch_trade_opr4_t1150_cap_ac_blk.csv, phase3_arch_trade_opr4_t1150_cap_blk.csv, phase3_arch_trade_opr5_t1150_cap_blk.csv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]
2026-09-13 Phase 4: option B checks (axial-centrifugal) and operability-method benchmark
    Check 1 (impeller stress, same gate solvers): both AC impellers pass disc/burst easily but fail
    exducer blade-root bending, worse than the pure centrifugal (1105 / 936 MPa at a 3.5 mm root vs
    620 MPa; tall exit blades b2/r2 0.43 / 0.30). ~10 deg backsweep would pass (not evaluated aero).
    Check 2 (operability: stacking model for the axial stage(s) + TurboFlow centrifugal and turbine
    maps + pyCycle): design surge margin 11 %, SLS steady running line meets the surge surrogate at
    ~90 % speed; robust to axial loss width and impeller throat size. The axial stage(s) set the peak.
    Benchmark: the same chain on the Phase 3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
    [phase4_benchmark_P400.csv, phase4_running_line_ax90000_opr4_t1150_ax1_pa1.5_cap_blk.csv, phase4_running_line_ax90000_opr4_t1150_ax2_pa2_cap_blk.csv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]
2026-09-14 basic perlimanary design for centrifigual jet engine has been reached phase 6
    [bearing_front.step, bearing_rear.step, compressor_casing.step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]
2026-09-15 Housekeeping: separate the axial work from the centrifugal baseline
    Quarantine the axial and axial-centrifugal work under axial/ (scripts, data,
    docs, plots, cad) so that continued development of the centrifugal baseline
    cannot pick up an axial number by accident. The centrifugal files keep their
    exact paths; no engineering result changes.
    Moved scripts keep two roots: ROOT still means the repo root (shared modules
    and shared data are reached through it, nothing is duplicated) and AXROOT is
    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
    [accel_ax80000_opr5_t1150_n6_cap_3r.csv, axial_vg_assembly.step, bearing_front.step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]
2026-09-15 README: project landing page with results and figures
    Rewrite README.md as a presentable overview: engine and aircraft results,
    the architecture trade, off-design on real maps, rotor dynamics and the 3D
    impeller FE, with the open risks stated plainly rather than buried.
    Moves the per-phase command reference to docs/running_the_code.md and brings
    its environment table up to date with the third (CAD) venv.
    Claude-Session: https://claude.ai/code/session_019ponkcpDx6k4HC3dbYjtFF
2026-09-15 Phase 7: afterburner - cycle, envelope, nozzle trade, closure and CAD
    Adds an afterburner to the frozen centrifugal engine, on the user's
    instruction and to the scope they chose: extend the envelope past Mach 1,
    and decide the variable nozzle by trading three concepts on numbers.
    Cycle model: cycle_model.py gains an `afterburner` option, OFF by default.
    With it off the model reproduces the frozen fielded dash point to 1e-16 on
    airflow and the real-map dry deck to 0.000 % at all ten Mach numbers
    (verify_ab_cycle.py, ab_envelope.py --regress). The second burn's heat
    release is cross-checked against Cantera to +1.35 %.
    Results:
    - +79 % net thrust at the dash (500 -> 896 N at Tt7 1900 K), TSFC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
    [ab_cad_mass.csv, ab_casing.step, ab_design_point.csv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]
